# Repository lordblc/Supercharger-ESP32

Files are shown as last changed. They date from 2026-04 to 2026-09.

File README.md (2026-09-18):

Ok, so.. I set out to build upon the work [skonk made that is referred to in this thread](https://www.electricmotorcycleforum.com/boards/index.php?topic=13489.0 "Electric Motorcycle Forum").

My goal was to achieve some additional abilities.  
I wanted to use better hardware. I found his approach to be very clunky and i could not see how I would make it fit on the bike.  
It didn't help that the CAN cable on the bike was very short and limiting me to basically place it close to the fusebox underneath the seat. An area that is already quite space limited.  
Anyway.. I also wanted to include HomeAssistant control as i already have that on my other chargeable vehicles.  

I tried to do the easy approach first, and simply employed CoPilot to just adapt the original code from Arduino to ESP32. This yielded a somewhat result but had issues.  
I referred to that result in the [same forumthread](https://www.electricmotorcycleforum.com/boards/index.php?topic=13748.0 "Electric Motorcycle Forum") as well as here.

Having kept at it and starting from scratch, I formulated an approach as a project manager and set out to make something with Claude as my assistant. I started using the Sonnet 4.5 model, but eventually moved on to Opus 4.6, and later Opus 4.7, Opus 4.8, Fable 5, Opus 5 and Fable 5.1(this code has yet to be updated).  
My approach was to always be in control of what was created and dividing the codebase into smaller chunks where I was able to keep up with what was suggested from the AI.

So, the details are as follows:  
I based this on the LilyGo T-2CAN which has 2 onboard, isolated CAN transceivers ready to go.  
It has 12-24VDC input so can be connected directly to the DC output from the chargers, eliminating one of the PSU's from the original. (I would still highly recommend using an isolated 5VDC for the bike connector to keep these as separate as possible.)  

The controller sits between the bike's CAN bus and the charger's CAN bus and manages the full charge cycle automatically.

Hardware

* [LilyGo T-2CAN (ESP32-S3)] (https://lilygo.cc/products/t-2can "LilyGo Website")
* Charger CAN bus: MCP2515 via SPI at 250 kbps
* Bike CAN bus: ESP32-S3 native TWAI peripheral at 500 kbps
' Tested with Elcon TC HK-J 3300W chargers; multiple units can run in parallel

Bike CAN Bus Interface

The firmware decodes the following from the Zero CAN bus:

* Pack voltage from both the Monolith (BMS 0x388) and PowerTank (BMS1 0x389)
* Pack current from both BMS units (0x408 / 0x409)
* Min and max battery temperatures from both BMS units (0x488 / 0x489), with a range filter to reject the non-thermocouple bytes that the Zero BMS puts in the same CAN frame
* Rated pack capacity in Ah from BMS pack config (0x288 / 0x289)

Charge Control

The charger is commanded over CAN with a target voltage ceiling and a current limit. The firmware implements a three-phase state machine:

* CC / Bulk: Constant current up to the configured power limit. Current ramps up gradually from zero at a configurable rate in W/s. Charge power is reduced as the pack voltage approaches the target through a lookup table (see below).
* CV / Absorption: Once the pack voltage reaches the target, the firmware holds the voltage ceiling and monitors actual charger output current. The charger self-regulates in this region.
* Float / Complete: CV phase ends when actual charger current drops below 2 A (after a minimum 2-minute settle period) or after a 20-minute timeout, whichever comes first. The charger is then stopped and the session is marked complete.  
The charger voltage ceiling is always set to the configured target, not the present pack voltage. This is important — setting it to the present pack voltage would leave the charger with no headroom and it would not regulate correctly.

One key difference here: When charging to 100% the controller will state being in "Bulk" all the way up to 100% but it will be relying on the voltage tables to regulate the power and you can see this reflected in the Current levels tapering off as it gets closer to 100%.

Protection and Cutback

Three lookup tables apply independent power cutbacks. All three are evaluated every cycle and the most restrictive limit wins:

* Voltage cutback: Reduces charge current progressively as the pack voltage approaches the target. The curve is intentionally aggressive toward the top end to avoid voltage overshoot. Thresholds are in decivolts of lifted (under-charge) pack voltage.
* Cold temperature cutback: Reduces charge rate based on the lowest thermocouple reading across both BMS units. Keeps the cells within safe charge rates when cold.
* Hot temperature cutback: Reduces and ultimately stops charging based on the highest thermocouple reading. Charging is stopped completely above 75 C.

Additional guards:

* The charger will not be commanded to start unless a valid pack voltage is present on the CAN bus, preventing phantom starts at boot or after CAN loss.
* Session Wh and Ah counters only accumulate when voltage, current, and a non-zero commanded current are all present simultaneously.
* The charger will throttle the current if the pack is too hot. It will go all the way to zero amps if the temp is too high. This protection also warns the user in the Dashboard.

Session Tracking

Accumulated Wh and Ah for the current charge session
Both CC and CV phase energy are counted using actual charger current, not commanded current

Web Dashboard

The firmware runs a web server on the ESP32. No external server is required. The dashboard shows:

Charging card: actual power, target power, charge current, charge mode (Absorption / Float / Complete)
Per-pack data: voltage, current, Ah capacity, min and max temperature — separately for Monolith and PowerTank
Session Wh and Ah totals
Configurable parameters: target voltage (V), power limit (W), ramp rate (W/s), number of chargers, C+ mode
Status data is delivered via a JSON API endpoint and the page auto-refreshes without a full reload.

WiFi and OTA

* Connects to a saved WiFi network on boot
* Falls back to access point mode if no saved credentials, allowing initial setup via browser
* mDNS hostname for easy access on the local network
* OTA firmware update via browser at /update, protected with HTTP Basic Auth
* MQTT and Home Assistant

Full MQTT discovery is included. The controller publishes itself to Home Assistant automatically with no manual YAML needed. (Tested with EMQX as MQTT server, should also work with mosquitto)

Read-only sensors published:

* actual_volts, target_volts
* monolith_volts, powertank_volts
* charge_amps, monolith_amps, powertank_amps
* monolith_ah, powertank_ah
* monolith_min_temp, monolith_max_temp, powertank_min_temp, powertank_max_temp
* charge_power, target_power_w, max_power_w
* watt_hours, coulombs
* charge mode / phase

Controllable entities:

* Target voltage (V) — number slider
* Target power (W) — number slider
* Ramp rate (W/s) — number slider
* Number of chargers — number slider
* Charging enabled — switch
* Architecture

The firmware uses FreeRTOS on the ESP32-S3 dual core:

Core 0 handles the bike CAN listener and charger CAN output to makes sure the heartbeat is never interrupted by web/mqtt handling clogging the cpu  
Core 1 handles the web server, charge ramp/control logic, and MQTT  
Shared state between cores is protected with mutexes. A 4 KB ring buffer log is available over serial and as a server-sent event stream in the browser.

Required Libraries

* mcp_can by coryjfowler
* PubSubClient by Nick O'Leary
* ArduinoJson by Benoit Blanchon (v6)
* ESP32 Arduino core (includes TWAI driver, ESPmDNS, Update)

Required software

* Arduino IDE with ESP32 board library
* Python (I did my setup initially with python-manager-26.1 for windows)

At current stage it should compile to ~1MB large binary file. I track changes through the VERSION tag that is also visible as reference on the dashboard.  

YOU NEED TO READ ```development_addon -> BUILD_SETUP.md``` AND DO THAT CONFIGURATION TO GET A WORKABLE .bin FILE.  
I cannot stress how important this is. It is directly tied to how OTA works and has been implemented as a safety feature. (stops others from uploading their own firmware)

And if you managed to read this far:  
using arduino_secrets.h is the quickest way to set everything up, but is not required. First boot without configured secrets will default to a welcome page to set everything up with a wlan ap that has the default password set to "12345678" and the AP SSID set to "Supercharger".

This document gets updated whenever there are new changes and i have the time to write them in here.  
DISCLAIMER: I might forget things by the time i get to updating here, but i am trying to keep this updated.

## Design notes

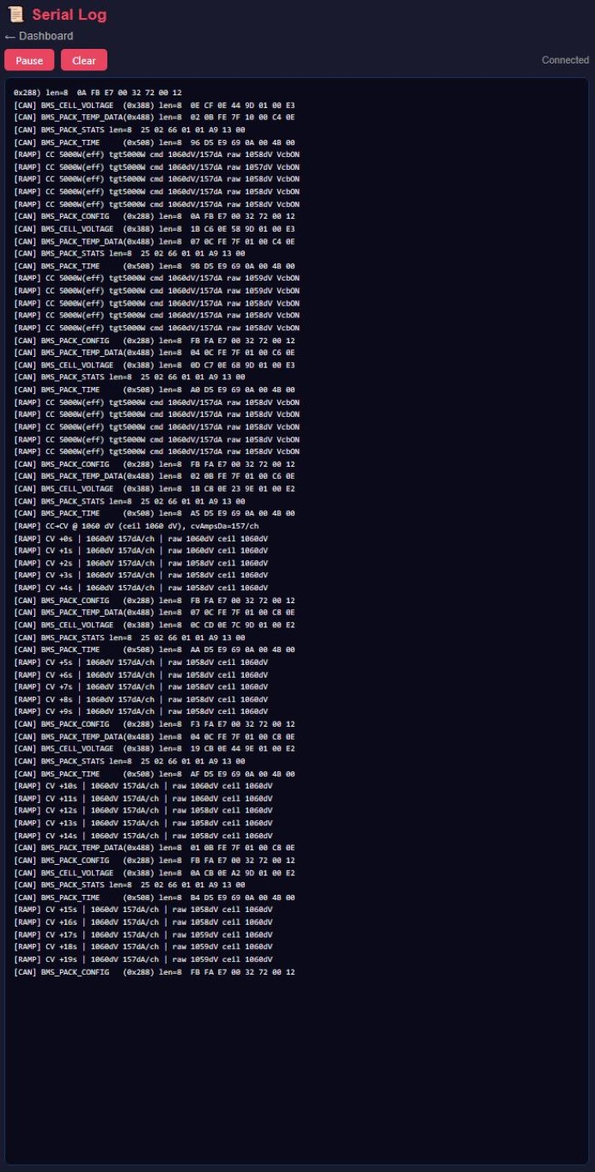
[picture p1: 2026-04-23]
pics/202604231420-Log_768.jpg

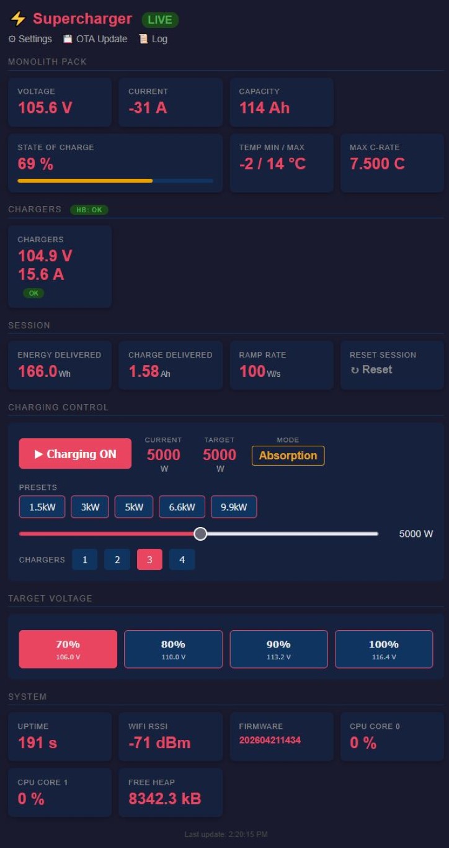
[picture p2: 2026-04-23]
pics/202604231420-Dashboard_Charging_Absorption_768.jpg

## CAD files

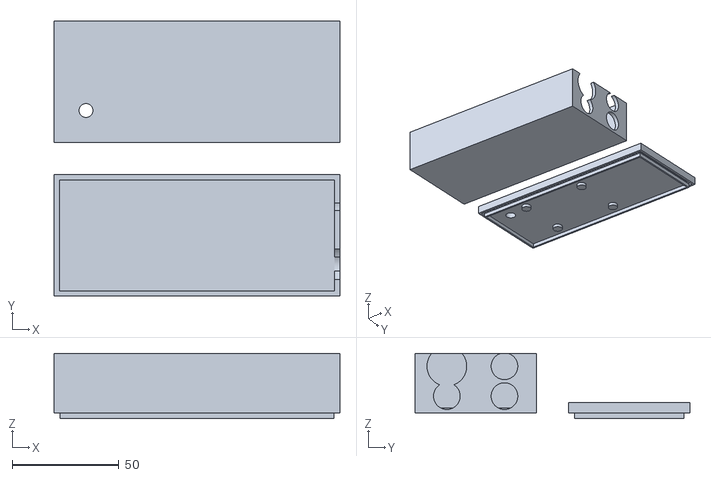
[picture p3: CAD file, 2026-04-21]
cases/supercharger_case_v1.stl
134.0 x 129.0 x 30.5

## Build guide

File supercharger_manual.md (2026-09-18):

# Supercharger 2.5 - ESP32 Controller

## User Manual

A WiFi connected CAN bus controller for charging a Zero motorcycle with up to 4 Elcon TC HK-J 3300W chargers in parallel. You get a web dashboard, optional Home Assistant integration, and firmware updates over the air.

The chargers can be powered from any AC source — a standard home outlet, a dedicated EVSE, or a public charge point. Tested at 3-phase 400 V via an **Easee charge robot** with full functionality.

---

## What changed in 2026-09

If you have used an earlier version, these are the differences you will notice:

- **Charge, Stop and Reset Session now ask first.** A small confirmation box appears in the page (not the browser's own pop-up) before charging starts or stops, before the session counters are zeroed, and before anything that reboots the controller — "Save WiFi & Restart" and the HTTPS toggle.
- **Buttons tell you the truth.** They grey out while the controller is answering, and if it could not do what you asked you get a message instead of silence: *"Controller busy — try again"* when it was mid-tick and applied nothing, and a jump to the login page when your session has expired. Previously the button just changed colour whether or not the command landed.
- **Log and OTA pages when HTTPS is on.** These two stay on plain HTTP by design. Their links now point at `http://...` automatically, so you no longer have to turn HTTPS off to update firmware or read the log.
- **"Keep me signed in" now has a 30-day limit.** A remembered login still survives reboots, but it is forgotten 30 days after you signed in. (If the controller has never had internet time — AP-only use — it has no clock to measure that against and the session keeps working.)
- **The 5–10 second BOOT hold now also signs out every device.** It still clears the saved WiFi network and restarts into AP mode; it additionally drops all logins, including remembered ones. Use it when handing the controller to someone else.
- Two new status banners — **Pack temperature unknown** and **Charger count mismatch** — plus a latched **Charger fault**. See [Status Banners](#status-banners).
- The cycle log's `total_ah` / `total_wh` columns are now per-cycle rather than running session totals — see [The cycle log](#the-cycle-log-cyclescsv).

---

## What You'll Need

- Supercharger 2.5 controller (LilyGo T-2CAN, ESP32-S3 based)
- 1 to 4 Elcon TC HK-J 3300W chargers (powered from any AC source — home outlet, EVSE, or public charge point; tested at 3-phase 400 V on an Easee charge robot)
- Zero motorcycle with CAN bus access to the BMS
- A 2.4 GHz WiFi network (optional, but recommended)
- A phone, tablet, or laptop with a browser for setup
 - A 5VDC Isolated PSU
 - A prototype board
 - A JAI Electronics MX23A18NF1 connector for the Bike connections
 - Some cables (i have used various.. the inter-board connections i could solve with a screened ethernet patch cord)
 - 2 male SuperSeal connectors:

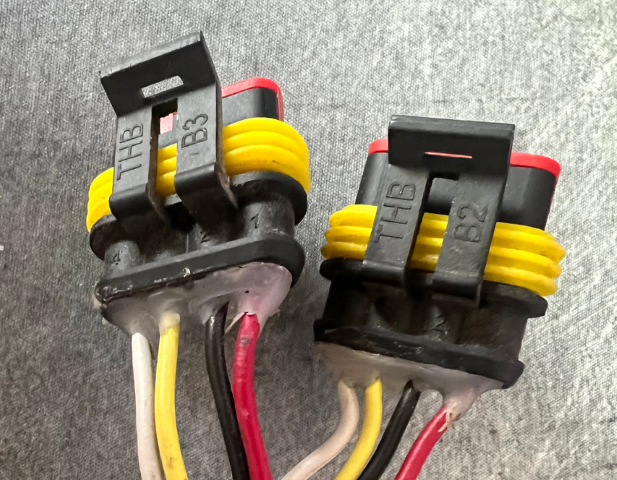
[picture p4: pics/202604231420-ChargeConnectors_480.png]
Charge Connectors


---

## Connecting the Hardware

**The LilyPad T-2CAN Connections**
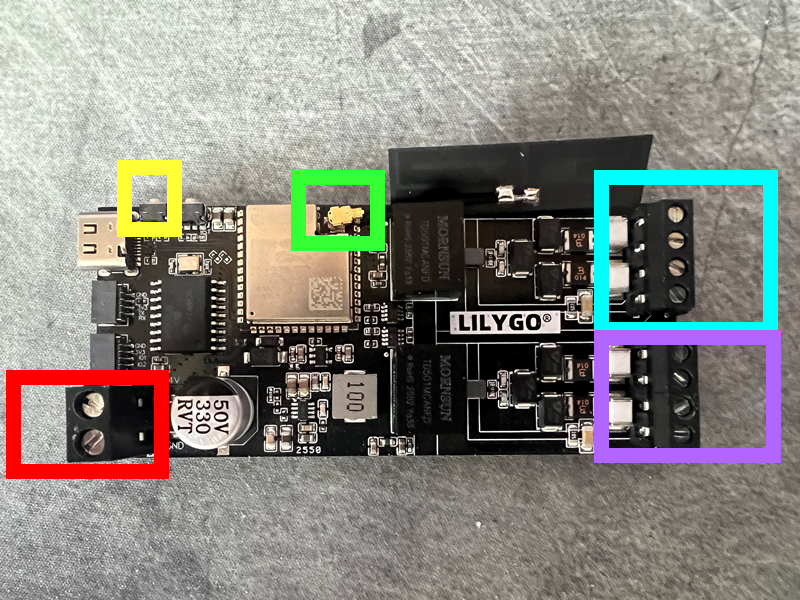
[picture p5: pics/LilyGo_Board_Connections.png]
LilyPad_Board_Connections


In the **Red square** you connect the **red** wire from the chargers to the screw-terminal closest to the USB-C connector. 
You then connect the **black** wire from the same connector to the other terminal, furthest away from the USB-C connector, at the board end.
**Yellow square:** This is the reset button. No connections here, just FYI to where you find it.
**Green square:** You connect the WLAN antenna here. 
**Turqoise square:** You connect the chargers CAN bus here, see seperate image for details.
**Purple square:** You connect the bike's CAN bus here, see seperate image for details.

**The LilyPad CAN Connections**
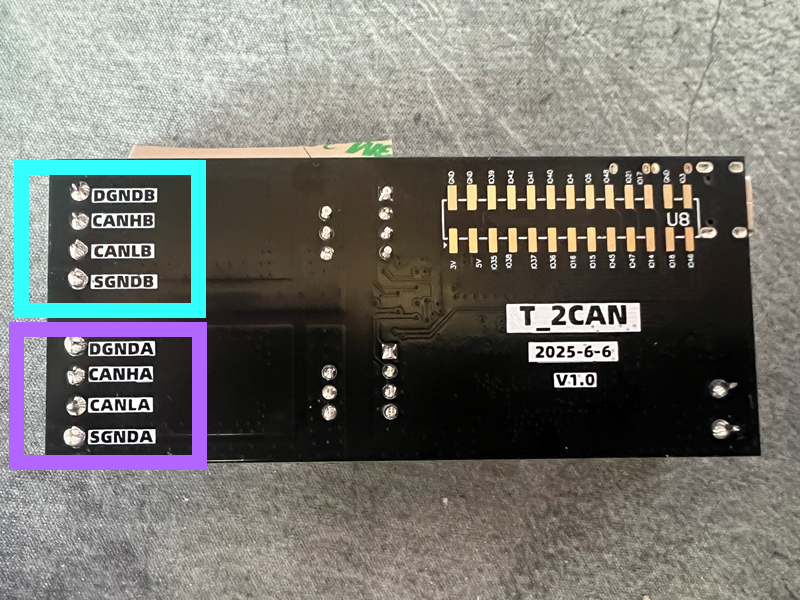
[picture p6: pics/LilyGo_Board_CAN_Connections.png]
Lilypad_Board_CAN_Connections


In the **Turqoise square** you connect the **CANL to the CANLB port** and the **CANH to the CANHB port**. (color code will come later once i have defined the other PCB)
You connect the **GND** cable that is also connected to the **12V-GND** power supply terminals to the **DGNDB** port. 

In the **Purple square** you connect the **CANL -> CANLA port** and the **CANH -> CANHA port** from the bike's CAN bus. Here you will also connect the **separated GND** from bike cable to the **DGNDA port**.

*[MORE TO BE WRITTEN]*

This section covers the 4 pin connector from the Elcon chargers, the 12 VDC supply, CAN bus wiring to the bike, and the splitters used for parallel charger builds.

---

## First Run

Once everything is wired up:

1. Power on the chargers. The 12 VDC from the Elcon cable feeds the controller.
2. The controller boots. Startup takes roughly 2 to 3 seconds.
3. On a fresh unit there are no saved WiFi credentials, so it falls back to AP (setup) mode. If you have connected a laptop to the USB-C port, you'll see a log line on serial saying `No credentials available. Starting AP mode.`
4. Move on to WiFi setup below.

If you want to watch it boot, connect a USB-C cable to the controller and open a serial monitor at 115200 baud.

---

## WiFi Setup (AP Mode)

On first boot, or any time the controller can't find a known network, it creates its own WiFi network for setup.

1. On your phone or laptop, scan for WiFi networks. Look for **Supercharger** (or whatever the builder set as `SECRET_AP_SSID` — see the arduino_secrets.h section below).
2. Connect to it. The default password is **12345678** (or `SECRET_AP_PASS` if the builder set one).
3. Your phone will probably warn you there's no internet. That's fine, ignore it.
4. Open a browser and go to **http://192.168.4.1** or **http://supercharger.local**.
5. You'll see a WiFi Setup page. Enter your home WiFi name (SSID) and password.
6. Hit **Save & Restart**.
7. The controller saves the credentials, reboots, and connects to your home WiFi.

Credentials are stored in non-volatile memory, so you only do this once per network. The AP name and password can also be changed at runtime from the **Settings** page once you're connected — handy if you want a stronger AP password but don't want to reflash.

### Switching to a Different Network Later

If the saved network is gone (moved house, router changed, etc), the controller will try the saved one for 15 seconds, fail, then fall back to AP mode on its own. From there, just redo the setup above with the new credentials.

If the old network is still around and you want to force setup mode anyway, hold the **BOOT** button on the controller for 5 seconds (see the next section). This wipes the saved WiFi credentials and reboots straight into AP mode.

### Fixed AP IP Address (optional)

By default the dashboard lives at **192.168.4.1** in AP mode but at a different, router-assigned address on home WiFi. If you've saved the dashboard as an "app" on your phone's home screen (see the iOS shortcut tip under *Logging In*), that shortcut is pinned to one address — so it only works on one of the two networks.

The **fixed AP IP** option solves this: it makes AP mode serve the dashboard at an IP you choose, so you can point it at the same address your home network gives the controller. One home-screen shortcut then works everywhere.

To set it up: **Settings → Access Point → "Use a fixed AP IP address"**. Tick the box and enter:

- **AP IP Address** — the address the dashboard should answer on (e.g. the address your home router reserves for the controller)
- **Gateway** — usually your home router's IP
- **Subnet Mask** — almost always `255.255.255.0`

Save, then reboot for it to take effect. When the box is unticked, AP mode uses the standard `192.168.4.1`.

Builders can also bake this in at compile time via `SECRET_AP_IP` / `SECRET_AP_GATEWAY` / `SECRET_AP_SUBNET` in `arduino_secrets.h` — see the builder section. The Settings page always overrides the compiled-in values.

### Using the Controller Without Home WiFi

The controller works fine without internet. It'll sit in AP mode and you can use the dashboard by connecting straight to the AP (default **Supercharger**). Everything local still works:

- Charger monitoring
- Power slider and presets
- Start / stop charging
- Battery data
- Live log viewer

Only Home Assistant integration and OTA updates need internet.

---

## The Buttons on the Controller

The LilyGo board has two small side-mounted buttons: **RST** and **BOOT**.

### RST (Reset)

Hardware reset, wired straight to the chip's enable pin. Pressing it cold-boots the controller — equivalent to cycling the 12 V supply from the chargers, just without unplugging anything. The firmware doesn't see the press; the chip simply restarts. Useful when the dashboard is unreachable and you want a clean restart without pulling cables.

### BOOT (User Reset / Recovery)

This is the one to remember. Four hold patterns are recognised:

| Hold time | Action | What it does |
| --- | --- | --- |
| **< 1 s** | Nothing | Ignored — prevents accidental triggers from packaging knocks. |
| **1 – 3 s** | Nothing (logged) | Logged to serial/SSE but no action taken. |
| **3 – 5 s** | Clear auth lock | If the dashboard login is locked (5 failed password attempts from one device, or the device-wide 15-failures-per-minute backstop), this clears all locks and fail counters so the login page becomes responsive again. Has no effect if no lock is currently active. |
| **5 – 10 s** | Clear WiFi + sign out all devices, restart into AP mode | Wipes the saved WiFi SSID/password **and every login session**, including "keep me signed in" logins saved to flash — so a browser that was remembered has to log in again. AP credentials, MQTT settings, charger count, ramp rate, target voltage, and boot defaults all stay intact. Use this when you need to switch the controller to a new network, or when handing it to someone else. |
| **10 s+** | Factory reset | Wipes the entire NVS configuration namespace — WiFi credentials, AP credentials, MQTT settings, charger count, ramp rate, target voltage, and boot defaults. The controller reboots immediately when the 10 s threshold is hit (you don't need to release), so you'll feel the reset rather than wonder if it took. Use this when re-homing the controller to another bike or troubleshooting a stuck configuration. |

The BOOT button still doubles as the chip's bootloader entry button if you happen to hold it while pressing RST — that puts the ESP32-S3 into USB download mode, which only matters if you're flashing over USB.

---

## Logging In

The dashboard is password protected. On first visit your browser shows a login form.

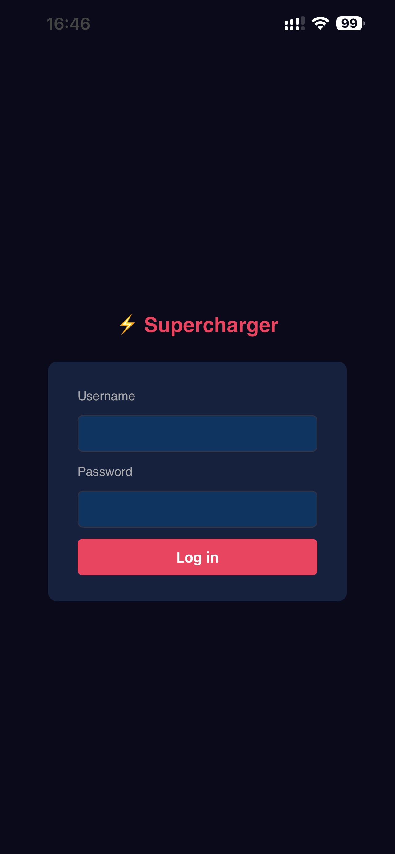
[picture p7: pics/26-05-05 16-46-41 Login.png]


- **Username**: set in `arduino_secrets.h` as `SECRET_OTA_USER`
- **Password**: set in `arduino_secrets.h` as `SECRET_OTA_PASS`

The login form works with your browser's built-in password manager — save the credentials once and it auto-fills on every return visit.

### Keep me signed in

The login form has a **"Keep me signed in on this device"** checkbox, ticked by default. It controls how long the controller remembers you:

- **Ticked** — the session lasts **30 days** and, importantly, **survives a reboot**. The controller cold-boots every time you power the chargers on, so without this your login would be forgotten between every charge session. With it ticked, the controller saves the session to its internal flash and you stay logged in across power cycles. This is what you want for an iOS home-screen shortcut — open the "app" and it's just there, no login prompt.
- **Unticked** — the session lasts **6 hours of idle time** and is **cleared on any reboot**. Use this on a shared or untrusted device.

Either way the session is cleared when you click **Logout** (top of the dashboard). To revoke *all* remembered devices at once — e.g. if a phone is lost — do a factory reset (hold BOOT 10 s+), which wipes all saved sessions along with the rest of the configuration.

While a dashboard tab is open and polling, the session stays alive regardless of the setting.

> **iOS home-screen "app" tip:** open the dashboard in Safari, tap Share → *Add to Home Screen*. You get an app-like icon that opens the dashboard full-screen. Pair it with "Keep me signed in" and the **fixed AP IP** option (see *WiFi Setup*) and the shortcut works the same whether you're at home or charging on the road.

### Login rate limiting and lock-out

Failed login attempts are tracked **per client device** (by IP address), so one misbehaving gadget on your network can't lock everyone else out:

| Attempt | Delay before next try |
| --- | --- |
| 1 – 2 | None (free) |
| 3 | 2 s |
| 4 | 5 s |
| 5 | 15 s — and the login is **hard-locked** |
| 6 | 30 s |
| 7+ | 60 s (cap) |

After **5 failures from one device** the login page returns **423 Locked** and refuses all further attempts from that device regardless of waiting.

On top of the per-device tracking there is a **device-wide backstop**: if **15 login failures from any combination of devices** land within one minute (the signature of someone hopping between addresses to dodge the per-device lock), the controller locks out **all** new logins for 15 minutes.

Three ways to clear either lock:

1. **BOOT button hold 3 – 5 s** — instant, no reboot required (see button section above). Clears the per-device locks, the fail counters, and the device-wide lock in one go.
2. **15 minute auto-clear** — both lock types clear themselves after 15 minutes with no manual intervention.
3. **Reboot** — power cycle or press RST.

Existing open sessions are not affected by a lock — if you are already logged in, the dashboard keeps working while the lock is active. Only new login attempts are blocked.

---

## Finding the Dashboard

Once the controller joins your home WiFi, the easiest way in is mDNS:

- **mDNS**: open **http://supercharger.local** in any browser on the same network. Works on Windows 10+, macOS, iOS, Android (most), and any Linux box running Avahi. No IP guessing required. Also works in AP mode — connect to the controller's AP and the same URL resolves to 192.168.4.1.
- **Router-assigned hostname**: the controller now identifies itself as `supercharger` in its DHCP request. If your router auto-registers DHCP client names into your local DNS (OpenWRT, pfSense, UniFi, MikroTik, etc.), the unit will also appear as `supercharger.<your-domain>` — e.g. `supercharger.iotnet` or `supercharger.lan`. This is a separate path from mDNS and works for any client on the network, including ones that don't speak mDNS.

If neither resolves (some corporate or guest networks block multicast and don't auto-register DHCP names), fall back to:

- **Serial log**: connect USB-C and open a serial monitor at 115200 baud. Look for a line like `[WIFI] Connected (prefs). IP: 192.168.1.42`.
- **Router**: log into your router's admin page and check the DHCP client list. The controller usually shows up as "espressif" or similar.

Type the IP into any browser on the same network and the dashboard loads.

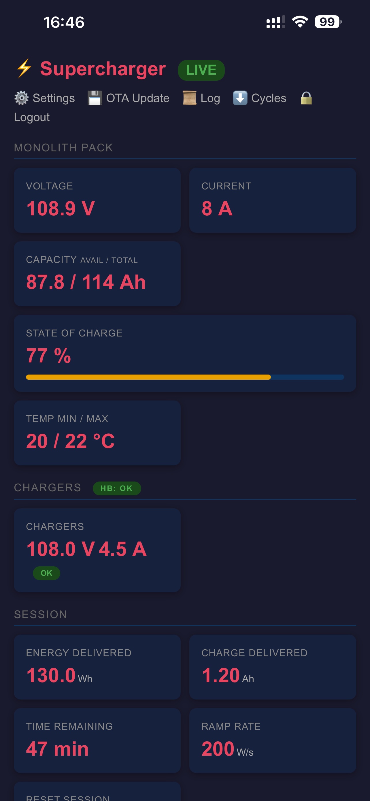
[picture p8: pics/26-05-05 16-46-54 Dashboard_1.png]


---

## Using the Dashboard

The dashboard auto refreshes every 2 seconds.

### Battery Sections

**Monolith Pack** shows voltage, current, capacity, state of charge, temperature, cell balance, and BMS board temperature. Always visible.

- **State of Charge** is read straight from the BMS (CAN frame `0x188` byte 0) — the same coulomb-counted number the bike's own dashboard uses, so the two should agree closely. If the BMS hasn't broadcast a status frame yet (typically the first few seconds after the bike wakes), the card falls back to a voltage-curve estimate and is labelled `(est.)` until the BMS catches up.
- **Capacity** shows `available / total Ah` — the available number is the nominal pack AH multiplied by the current SoC, so it tracks how much charge is actually left in the pack right now (e.g. `57.0 / 114 Ah` at 50%) rather than just printing the constant nameplate value.
- **Cell Balance** shows the spread between the highest and lowest individual cell voltage in the pack (max − min, in mV). The BMS broadcasts one cell at a time on CAN frame `0x388`, cycling through all 28 cells roughly every 3 seconds; the controller accumulates all readings and keeps the balance current. The value is colour-coded:
  - 🟢 **Green** — less than 10 mV: cells are well-balanced, no action needed.
  - 🟡 **Amber** — 10 – 50 mV: mild imbalance, worth watching over time.
  - 🔴 **Red** — more than 50 mV: significant imbalance; consider a full charge to 100 % to let the BMS balance.
  The tile shows "—" for the first few seconds after the bike is connected, while the controller is still collecting the first full round of cell readings.
- **BMS Temp** shows the temperature of the BMS circuit board itself (CAN frame `0x488` byte 1 — reported as "Controller Temp" by third-party diagnostic tools). This is separate from the min/max cell temperatures in the Temp card, which reflect the cell pack interior.

**PowerTank Pack** shows the same fields (except cell balance and BMS Temp, which are not decoded for the PowerTank) if a PowerTank is present. It's auto detected within 10 seconds of the first bike CAN frame. If it doesn't show up in that window, the section stays hidden.

### Status Banners

A coloured banner across the top of the dashboard tells you when something needs your attention. The colour tells you how serious it is:

| Colour | Meaning |
| --- | --- |
| **Red** | Charging has stopped, or cannot start. |
| **Amber** | Charging continues, but at reduced power. |
| **Blue** | Advisory only. Charging is unaffected. |

Only one banner shows at a time — the most serious condition wins, so you never get two messages that contradict each other. Each one clears itself as soon as the condition passes and needs no acknowledging — with one exception: **Charger fault** is latched, and only clears when you switch charging off and on again.

Separately from these, a red **"No WiFi"** banner means the controller can't reach your home WiFi and is running its own AP. Reach the dashboard via `http://<ap-ip>` or `http://supercharger.local`. It reconnects automatically when home WiFi comes back.

#### Red — charging has stopped



| Banner | What it means | What to do |
| --- | --- | --- |
| **Pack too cold** | Pack is below **0 °C**. Charging a cold lithium cell plates metallic lithium onto the anode, which permanently reduces capacity and can eventually short the cell. This is the one limit you should never work around. | Nothing. Charging resumes on its own once the pack warms past 2 °C. Riding the bike, or moving it somewhere warmer, is the quickest way. |
| **Pack too hot** | Pack is above **45 °C**, the cell manufacturer's charging limit. | Nothing. Resumes on its own below 43 °C. If it happens without hard riding beforehand, check for blocked airflow around the pack. |
| **Pack voltage too low** | Pack is below **70 V** (2.5 V per cell). Below this level the copper current collector inside the cells starts to dissolve, and charging normally can create an internal short. | **Do not force it.** This should never happen in normal use — the bike's own BMS cuts out well above this. Have the pack checked by a technician. |
| **Pack temperature unknown** | The BMS is not reporting a valid pack temperature — the sensor is reading as disconnected, or the frame carrying it has stopped arriving. Without a temperature the hot cutback and the 45 °C limit have nothing to work from, so the controller will not charge. | Nothing, if it's brief — charging resumes as soon as valid temperature data returns. If it persists, the pack's temperature sensor or its wiring needs checking. |
| **No data from bike** | The controller has lost contact with the bike's BMS, so it can't see pack voltage or temperature. It will not charge blind. | Check the charge connector is fully seated and the bike is powered on. Charging resumes within a second of data returning. |
| **Charger fault** | A charger is reporting a **hardware fault or an over-temperature**, or its output voltage has run well above the voltage asked for. (The other things an Elcon reports — AC input out of range, "no battery yet", comms timeout — are shown on the charger card but deliberately do *not* stop a charge: they come and go on their own.) A fault has to persist for three seconds before it counts, and the first five seconds after you press Charge are ignored, because a charger that has been sitting idle reports its starting state until it has seen a few commands. | Find and fix the cause (see the charger's own status card), then press **Stop** and **Charge** again. This one does *not* clear itself: it stays latched until charging is switched off and back on, so a unit that faults and then drops off the bus can't quietly resume. |
| **Charger count mismatch** | More chargers are answering on the CAN bus than the charger-count setting says are installed. Since all units get the same broadcast command, each extra one delivers a full share on top of what was asked for. | Set the charger count in Settings to match what's actually connected. Charging resumes as soon as the two agree. |
| **Too many chargers** | More than four chargers are answering on the CAN bus. The controller divides commanded current between the chargers it knows about, so an extra unit would make every charger deliver more than intended. | Disconnect the extra charger, or give the chargers distinct CAN instance IDs, before charging. |

#### Amber and blue — charging continues



| Banner | What it means | What to do |
| --- | --- | --- |
| **Reduced power — pack warm** | Pack temperature has crossed the hot-cutback threshold and power is being trimmed back. Normal on a hot day or after a fast ride. | Nothing. It speeds back up as the pack cools. |
| **Reduced power — at cell current limit** | The power you asked for needs more current than the cells are rated to accept (1 C), so it has been capped. | Nothing, unless you'd rather not sit at the limit — in which case lower the power setting. |
| **Ignoring bad data from bike** | Some CAN messages from the battery are arriving corrupted and are being discarded rather than acted on. | Nothing if it's occasional. If it persists, check the CAN wiring and connector for damage or a loose shield. |

### Chargers

One card per detected charger, with voltage, current, and status. Chargers appear automatically within a few seconds of being connected. A heartbeat badge at the top shows whether the controller is successfully talking to the bus.
**NOTE:** The DigiNow pack this was programmed against, came with one(and same) ID programmed towards all 3 chargers. If you have this setup, the system will only detect one charger, but you can set this static as a work-around.

### Charging Control

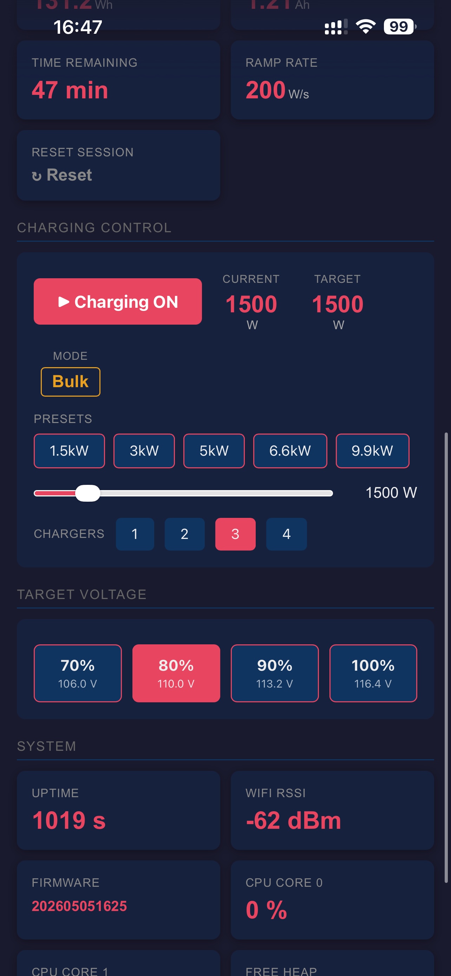
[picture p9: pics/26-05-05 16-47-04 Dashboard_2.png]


**ON / OFF button**: enables or disables charging. When disabled, the controller commands zero power immediately, no ramp down.

**Power slider**: set your target power in watts. The controller ramps from current to target at 50 W(adjustable) per second, so jumping from 500 W to 3300 W takes about a minute to get there. This is intentional.

**Preset buttons**: auto scale based on how many chargers you have connected. Just tap one to jump to that power.

Presets per charger count:

| Chargers | Preset 1 | Preset 2 | Preset 3 | Preset 4 | Preset 5 |
| --- | --- | --- | --- | --- | --- |
| 1 | 500 W | 1000 W | 1650 W | 2200 W | 3300 W |
| 2 | 1000 W | 2000 W | 3300 W | 4400 W | 6600 W |
| 3 | 1500 W | 3000 W | 5000 W | 6600 W | 9900 W |
| 4 | 2000 W | 4000 W | 6600 W | 8800 W | 13200 W |

The preset number (1–5) stays consistent across charger counts — Preset 2 always represents the second-lowest power level for however many chargers you have. This is also the column used for the Boot Defaults preset setting (see Settings page below).

**Chargers 1 / 2 / 3 / 4 buttons**: these set how many chargers the controller accounts for when scaling the preset table and the slider's maximum. They have **no effect on what the chargers actually do** — the controller broadcasts a single CAN command and all chargers that share the same CAN ID respond to it simultaneously, regardless of this setting. This is the typical DigiNow setup where all chargers are programmed with the same ID. If your chargers each have a *distinct* CAN ID, this count would become meaningful and the button should be left at the number physically connected rather than adjusted freely.

**Auto behavior**: when chargers first appear, the controller auto enables charging at the lowest preset. When they all disappear (e.g. you unplug), it auto disables. You don't have to babysit it.

### Charge Limit Presets (% of Full)

Below the power slider you'll find a row of **70 / 80 / 90 / 100 %** buttons. These set the **target pack voltage** — i.e. how full the controller will let the pack get before it stops feeding it. They are the key knob for trading range against pack longevity, and they directly drive the CC / CV state machine described below.

| Preset | Pack voltage ceiling | Roughly what it gives you |
| --- | --- | --- |
| 70 % | 106.0 V | Daily commute / short rides. Easiest on the cells; a useful default if the bike sits for days between rides. |
| 80 % | 110.0 V | Recommended day-to-day setting. Most of the range, much less stress than topping right out. |
| 90 % | 113.2 V | Longer rides. A gentle compromise. |
| 100 % | 116.4 V | Use the day before a long ride or for periodic balancing. The pack will sit slightly hot and at full voltage, which accelerates calendar ageing if you leave it there for days. |

The percentages are based on the Zero monolith pack open-circuit voltage curve (28S Li-ion NMC). The mapping is not perfectly linear with state of charge (Li-ion never is), but it's close enough that "80 %" lands you near 80 % SOC.

The dashboard remembers your last selection across reboots. The same setting is exposed over MQTT (`target_volt_v`) for Home Assistant automations — e.g. set 100 % only the night before a trip.

### Bulk / Absorption / Float — How the Controller Stops Charging

The controller runs a three stage automatic charge cycle, named after the standard solar/battery-charging convention so what's happening on the bike maps to what you'd expect from any other smart charger.

**Stage 1 — Bulk** *(internally CC, "Constant Current")*
This is the main charging phase where most of the energy goes in. The controller commands the chargers to deliver the power you've set on the slider, ramping up at 50 W/s (adjustable). Pack voltage rises gradually as the cells absorb energy. The dashboard phase indicator reads **Bulk**. Voltage and temperature limits (see `battery_tables.h`) only apply in this phase — they trim power back as the pack gets close to full or warm.

**Stage 2 — Absorption** *(internally CV, "Constant Voltage")*
When the pack reaches the target voltage, the controller switches to **Absorption**. It holds the pack at that voltage and lets the chargers reduce current as the cells equalize and finish topping up. You'll see the current target falling on the dashboard while charging continues at a lower level. This stage finishes when one of two things happens, whichever comes first:

- Actual delivered current drops below **2 A total** (after a 2 minute settling window).
- **1 hour safety timeout** finishes.

The 1 hour timeout is generous on purpose — better to give all cells a long, well-paced equalization than to cut absorption short. The absorption stage is short at 70–80 % targets and longer at 90–100 %, because higher charge levels need more time to equalize across the pack. Lower presets shorten or eliminate this stage entirely. That's why 70 % or 80 % charges take proportionally less time. Most cell stress happens during absorption at over 90 % charge — lower presets avoid most of it.

**Stage 3 — Float** *(internally DONE)*
Charging stops, the chargers go silent, and the cells rest. The dashboard shows **Float**. Energy totals (Wh, Ah) stop updating. The controller stays in this stage indefinitely until either the user turns charging off, or the pack sags below the re-engage threshold (see below) and a new cycle starts.

**Time Remaining card** (Session row): a coulomb-counting estimate of how much longer charging will take to reach the active **target preset** (not 100 %). It's the same idea as the bike's own dashboard timer, but it tracks the user-chosen ceiling. During Bulk it divides the remaining Ah by the present pack current and smooths the result with a small EMA filter so a brief current dip doesn't jump the readout. During Absorption it shows the remainder of the 1 hour safety countdown — that's the upper bound; the stage usually ends earlier on the current taper. Reads "—" when the controller has no useful number to show (e.g. before current settles, or once the pack is already at/above the target).

Note that this isn't "float" in the lead-acid sense of holding a maintenance voltage on the pack — Li-ion doesn't want that. It's a *resting* float: the chargers are off and the BMS is left alone. The name keeps the dashboard consistent with what most users already know from solar / RV setups.

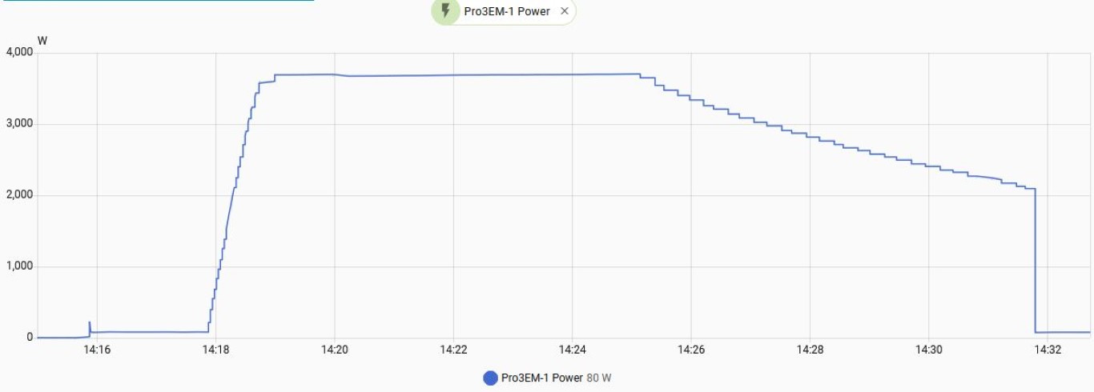
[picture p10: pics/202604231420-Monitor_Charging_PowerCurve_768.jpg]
Dashboard Screenshot


Screenshot from my Home Assistant power monitor. This monitor sits in front of the 230 V → 400 V transformer, so the absolute watts aren't precise — but it does cleanly show the bulk ramp-up, absorption taper, and float (charger off) stages.

**Recovery transitions** — the controller doesn't just sit in Float forever:

- **Absorption → Bulk** if pack voltage drops more than 1 V below the limit after switching to Absorption, it switches back to Bulk.
- **Float → Bulk** the threshold depends on the preset you've chosen:
  - **70 % or 80 %**: pack must drop more than **2 V** below the target before a new cycle starts. Frequent small top-offs are fine in this gentle SoC range.
  - **90 %, 100 %**, or any custom target above 110.0 V: the controller waits for the pack to sag all the way down to the **80 % level (110.0 V)** before re-engaging. The cycle is wider (more voltage sag per top-off), but the pack spends far less time hovering near full charge — which is what actually wears Li-ion cells. The trade-off is deliberate: at 100 %, you'll see the pack discharge from 116.4 V down to 110.0 V before the chargers kick back in.

**Already at target when you start**: if you turn charging on and the pack is already at or above the chosen preset's voltage (e.g. you set 80 % but the bike is at 84 %), the controller skips Bulk and Absorption entirely and goes straight to **Float** without ever sending a start command to the chargers. The same Float → Bulk re-engage rules above then decide when (if ever) to start a new cycle. No wasted brief charge bursts at the top of the SoC range.

Bulk's first job at the start of every session is this comparison, and it waits for real telemetry before making it — so if the controller powers up with charging already enabled (see Boot Defaults) but the bike's BMS hasn't reported in yet, the decision is deferred a tick rather than skipped. The serial log records which way it went:

```
[RAMP] Start: no charge needed - pack 1112 dV (~84%) >= target 1100 dV (~80%). FLOAT; will top up if the pack sags.
[RAMP] Start: BULK - pack 1050 dV (~68%) -> target 1100 dV (~80%)
```

#### Changing the target mid-charge

You can move the % preset at any time and the controller re-evaluates immediately — you don't have to stop and restart charging.

| You change the target to… | Pack is… | What happens |
| --- | --- | --- |
| **A higher preset** (e.g. 80 → 100 %) | below the new target | Returns to **Bulk** and carries on charging, from Float or from Absorption. |
| **A higher preset** | already within 1 V of the new target | Stays where it is. Not worth a whole cycle for under a volt. |
| **A lower preset** (e.g. 80 → 70 %) | above the new target | Goes straight to **Float**. The chargers stop; no partial cycle at a voltage the pack is already past. |
| **A lower preset** | still below the new target | Keeps charging, and stops at the new lower ceiling. |

After dropping to a lower preset, the normal Float → Bulk re-engage rules take over — so at 70 % the pack has to sag to 104.0 V before a fresh top-off begins. Lowering the target never leaves the controller stuck: a lower ceiling only makes the re-engage threshold lower too, and the pack always sags there eventually.

**Practical implication of the % presets**: choosing 70 % doesn't just mean "stop earlier" — it also means a much shorter Absorption phase (or none at all if the ceiling is below where the pack would naturally taper). That's why low presets feel quick: the bulk of cell stress in a Li-ion charge is during Absorption at high voltage, and you're skipping most of it.

### Cell Protection Limits

Everything above is about *how much* you charge. This section is about the hard boundaries the controller will not cross regardless of what you ask for.

The Zero monolith uses **Farasis IMP06160230P25A** cells — 25 Ah NMC pouch cells, 28 in series. The limits below come straight off that cell's datasheet, and they override the power slider, the presets, MQTT commands and the boot defaults alike.

| Limit | Value | Why |
| --- | --- | --- |
| Charging temperature | **0 to 45 °C** | Datasheet charging range. Below 0 °C charging plates lithium; above 45 °C it accelerates cell degradation. Outside this range the controller refuses to charge at all and shows a red banner. |
| Maximum charge current | **1.0 C** (25 A per cell) | Datasheet maximum. Applied to the *total* pack current before it's divided between chargers, so it holds no matter how many chargers are connected or what the cutback tables allow. |
| Minimum pack voltage for charging | **70 V** (2.5 V/cell) | Below this the copper current collector inside the cells dissolves and charging can create an internal short. The controller refuses; this needs a technician, not a charger. |
| Maximum pack voltage | **116.4 V** (4.157 V/cell) | The 100 % preset. Inside the cell's 4.15–4.20 V constant-voltage window, with margin. |

Two things worth understanding about how these interact with the cutback tables in `battery_tables.h`:

- The **cutback tables shape** charge current inside the safe window — they taper power as the pack warms or approaches full. The **hard limits above are the boundary** of that window. Two independent layers: if a future firmware change broke one, the other still holds.
- A temperature limit being hit is an **outright stop**, not a cutback. That's the difference between the red "Charging paused" banners and the amber "Reduced power" one. Amber means it's still charging.

**Sub-zero charging is not user-overridable.** There is no setting to bypass it, deliberately. If you need to charge a cold pack, warm the pack — ride it, or move the bike indoors.

**Implausible readings are discarded.** Pack voltage arriving from the bike outside 42–117.6 V (1.5–4.2 V/cell) is treated as a corrupted CAN frame and thrown away rather than acted on. If corrupted frames keep arriving, the blue "Ignoring bad data" banner appears; if they're *all* corrupt the controller ends up with no fresh data and stops charging with the red "No data from bike" banner. Either way it never computes a charge current from a bad voltage reading.

### System Info

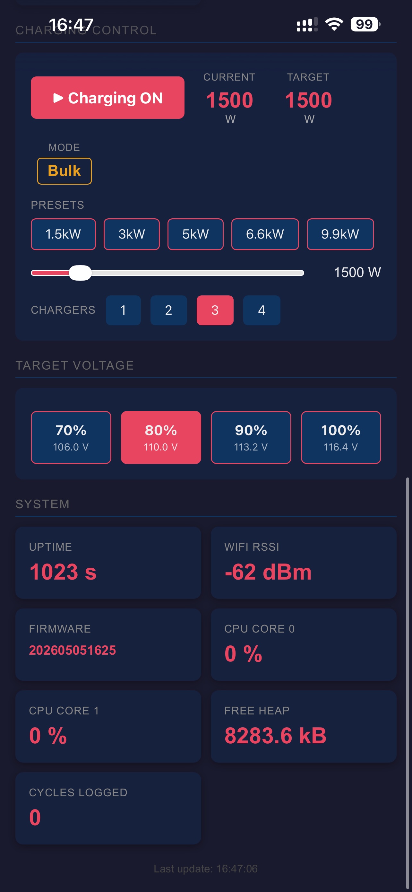
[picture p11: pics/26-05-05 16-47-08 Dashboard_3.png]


At the bottom: uptime, WiFi signal, firmware version, CPU load per core, free heap, and the number of charge cycles logged to the on-device data file. Useful when you're debugging.

#### The cycle log (`/cycles.csv`)

One row is appended per **completed** charge cycle — that is, a cycle that actually ran an absorption phase and finished in Float. A charge that never entered absorption (for example, the pack was already above the target when you pressed Charge) is not recorded. Download it with **⬇ Cycles** on the dashboard.

**A row is one bulk → absorption → float leg, not one plug-in.** Anything that sends the controller back to Bulk starts a fresh row: pressing Stop and then Charge again, a top-up after the pack has sagged out of Float, or the pack briefly sagging under load during absorption. So a single evening on the charger can produce several rows, and a leg that gets interrupted before reaching Float is simply not written. Don't add the rows up to get "energy delivered this plug-in" — they are per-leg figures.

The columns are: `timestamp, preset_pct, start_v, end_v, start_soc, end_soc, start_temp, end_temp, total_ah, total_wh, bulk_min, absorption_min, charger_count, abort_reason`.

`abort_reason` says how absorption ended:

| Value | Meaning |
|---|---|
| `0` | `current_taper` — absorption ran to completion, charge current tapered to the finish threshold. This is the normal, healthy ending |
| `1` | `cv_timeout` — absorption hit its one-hour safety limit and was stopped. The cells may not have finished balancing |
| `2` | `above_target` — absorption was cut short because the pack ended up above the target voltage: either you lowered the charge limit mid-charge, or the pack was lifted above it from outside (charged elsewhere, or regen) |

> **Changed in this version — `total_ah` and `total_wh` are now per-cycle.**
> They record the amp-hours and watt-hours delivered **by that leg alone**, accumulated tick by tick from the moment bulk charging started. Pressing **Reset Session** in the middle of a charge no longer affects them — that button zeroes the dashboard's session counters only, and the figures written to the cycle log are kept separately. In earlier firmware these two columns carried the running *session* totals instead, so any cycle that followed another one without a session reset in between reported everything accumulated since the reset, not just its own charge. Rows written by older firmware are still in the file and still session-to-date — if you are analysing a mixed file, treat rows older than this firmware's first entry accordingly. `total_ah` also no longer wraps above 655.35 Ah.

### Log Viewer

Click the Log link, or go to **/log**. Live serial log in your browser, updated in real time. Good for diagnosing CAN bus issues without needing a USB cable.

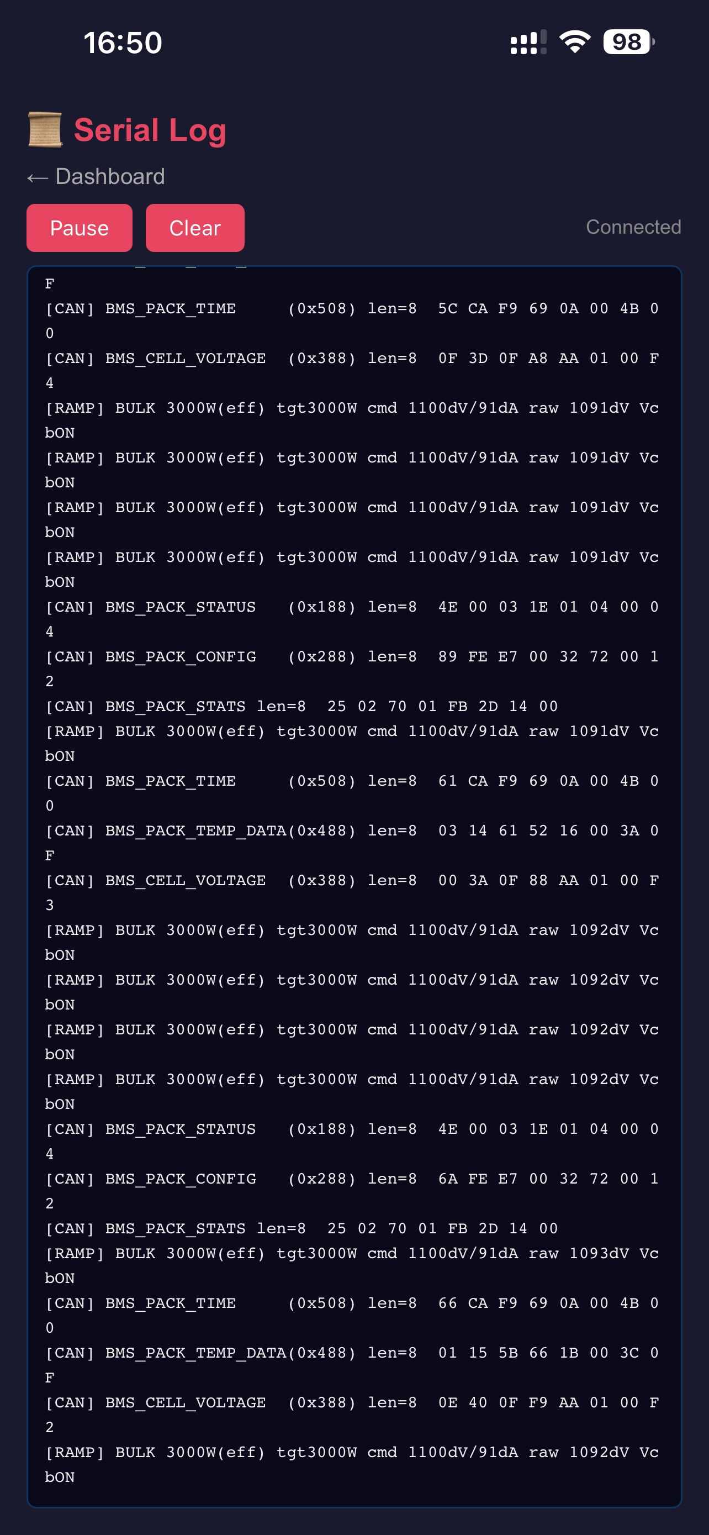
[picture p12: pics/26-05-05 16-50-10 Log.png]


---

## Settings Page

Click **Settings** in the dashboard navigation bar, or go to **/settings**. All settings are saved to non-volatile storage immediately — they survive reboots and OTA updates.

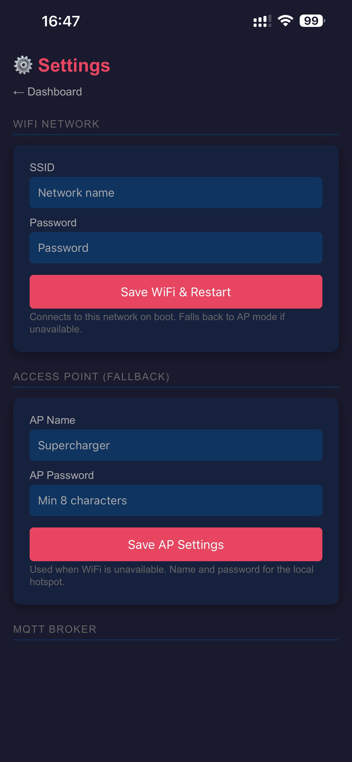
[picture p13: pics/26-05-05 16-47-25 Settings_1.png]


### WiFi Network

Set the SSID and password for the home WiFi network the controller should join. Changes require a restart (the save button triggers one automatically).

### Access Point (Fallback)

The name and password for the controller's own hotspot, used when home WiFi is unavailable. Minimum 8 characters for the password. The built-in default is `Supercharger` / `12345678` — change this if the device will be used in shared spaces.

**Use a fixed AP IP address** — tick this to make AP mode serve the dashboard at a specific IP instead of the default `192.168.4.1`. Enter the **AP IP Address**, **Gateway**, and **Subnet Mask** (usually `255.255.255.0`). The point is to mirror your home network so a single iOS home-screen shortcut works in both AP mode and on home WiFi — see *Fixed AP IP Address* under WiFi Setup. The change applies on the next reboot. Leave the box unticked to keep `192.168.4.1`.

### MQTT Broker

Configure the broker address, port, username, and password for Home Assistant integration. TLS (SSL) can be enabled — if you enable it you must also paste the broker's CA certificate (PEM format) into the text area that appears. Saving reconnects the MQTT client immediately without a reboot.

### Charger Hardware

Sets how many chargers the controller expects to see on the CAN bus (1 – 4). This controls which row of the preset table is used and divides the commanded current evenly across units.

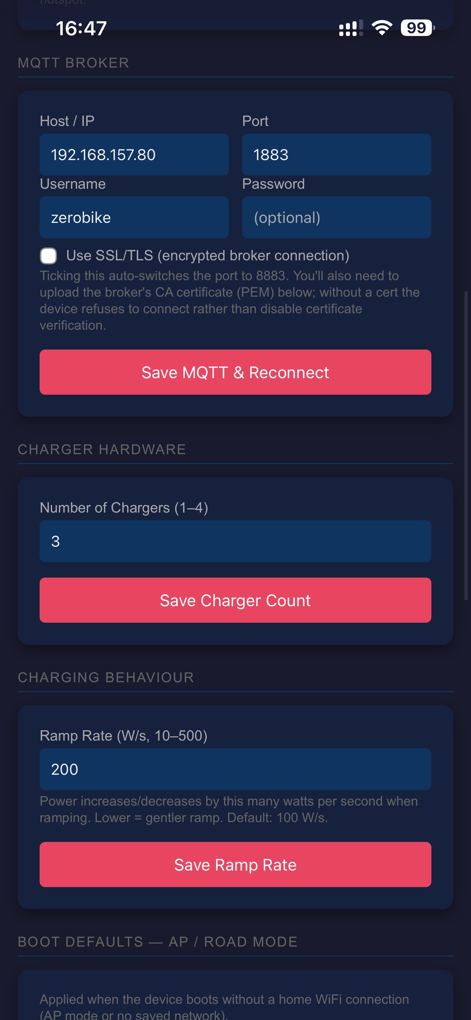
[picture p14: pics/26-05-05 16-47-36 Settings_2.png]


### Charging Behaviour

**Ramp Rate (W/s)**: how many watts the controller adds or removes per second when stepping toward a new target. Lower values give a gentler ramp. Default is 100 W/s; valid range 10 – 500.

### Boot Defaults — AP / Road Mode

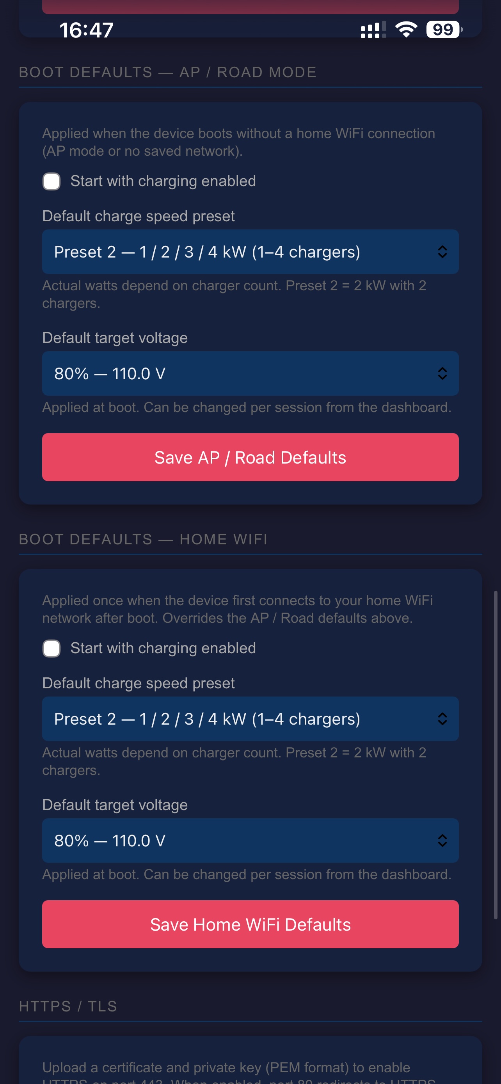
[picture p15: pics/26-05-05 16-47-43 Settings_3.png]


These settings define the charging state the controller wakes into on every boot **when no home WiFi connection is available** (AP/road mode). They are applied immediately in the boot sequence before any WiFi connection is attempted.

| Setting | What it controls |
| --- | --- |
| **Start with charging enabled** | If checked, charging is active as soon as the controller boots. If unchecked, you must press ON from the dashboard. Default: off. |
| **Default charge speed preset** | Which preset column (1 – 5) to use as the initial power target. Actual watts depend on charger count — see the preset table above. Default: Preset 2 (1 / 2 / 3 / 4 kW). |
| **Default target voltage** | Which charge limit preset (70 / 80 / 90 / 100 %) to start with. Default: 80% (110.0 V). |

Click **Save AP / Road Defaults** to persist. These take effect on the next boot.

**With "Start with charging enabled" on**, the controller still checks the pack against the target before doing anything — it waits for the bike's BMS to report in, compares pack voltage to the target preset, and goes straight to Float if no charge is needed. So booting with charging enabled and a pack already above the target does *not* produce a brief charge burst. If the BMS is slow to report, the decision is deferred rather than skipped.

### Boot Defaults — Home WiFi

The same three settings, applied **once** when the controller first joins your home WiFi network after boot. They override the AP / Road defaults above at that moment. Subsequent WiFi drops and reconnects during a session do not re-apply them — once applied they stay applied for that session only.

| Setting | What it controls |
| --- | --- |
| **Start with charging enabled** | As above, but for home WiFi sessions. |
| **Default charge speed preset** | As above, but for home WiFi sessions. |
| **Default target voltage** | As above, but for home WiFi sessions. |

Click **Save Home WiFi Defaults** to persist. These take effect on the next boot once the controller connects to home WiFi.

**Typical use**: set the AP / Road defaults conservatively (charging off, low preset, 80% target) for when the controller is connected to the bike at an unfamiliar location. Set the Home WiFi defaults to your preferred daily charging behaviour (charging on, your usual preset, 80% target) so you don't have to touch the dashboard each time you plug in at home.

### HTTPS / TLS (Optional)

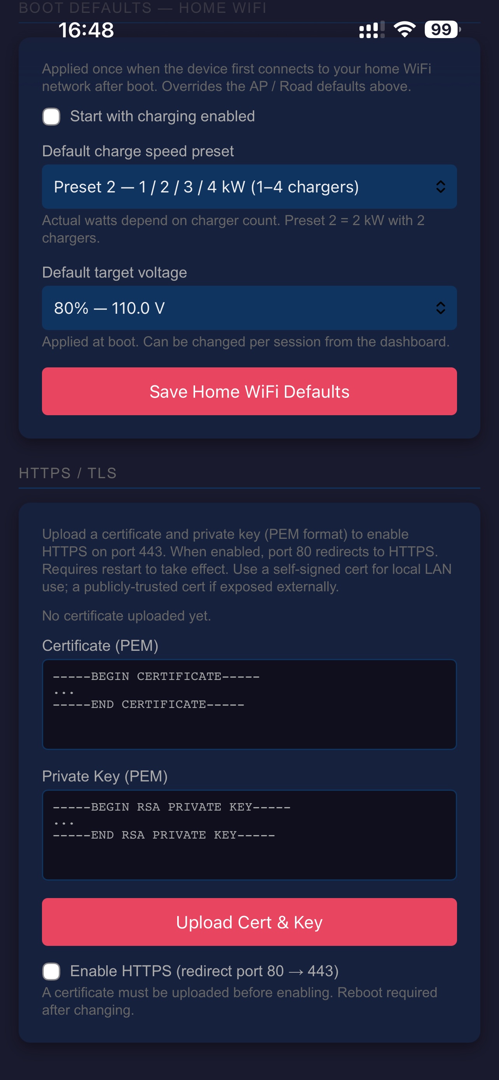
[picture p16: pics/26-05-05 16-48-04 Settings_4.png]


The controller can serve the dashboard over HTTPS (port 443) with a TLS certificate you supply. When enabled, port 80 redirects all traffic to port 443.

**Setup — one time per certificate:**

1. Generate or obtain a certificate and private key in PEM format. A self-signed cert is fine for a LAN device.
2. Open **Settings → HTTPS / TLS**.
3. Paste the certificate PEM into the **Certificate** box and the private key PEM into the **Private Key** box.
4. Click **Upload Cert & Key**. The PEM data is saved to NVS on the controller — it survives reboots and OTA updates.
5. Tick **Enable HTTPS** and confirm. This saves a flag to NVS.
6. Reboot the controller (RST button or power cycle). Port 443 starts automatically.

**Notes:**

- First browser visit to `https://<ip>/` will show a security warning for a self-signed cert. Accept it once (add a permanent exception). After that the browser connects silently.
- To disable HTTPS: untick **Enable HTTPS** in Settings (or POST `{"enabled": false}` to `/api/tls`) and reboot. The controller falls back to plain HTTP on port 80.
- `/update` (OTA), the live log stream (`/api/log/stream`), the log viewer page (`/log`) and the old `/save` setup form stay on **plain HTTP port 80** even when HTTPS is active — there is no TLS story for a multipart firmware upload or a long-lived log stream. You do **not** need to disable HTTPS to reach them: the dashboard's **Log** and **OTA** links switch themselves to `http://<address>/...` when the page was loaded over HTTPS, so they just work. The login page is also served on port 80 for the same reason, so these pages can sign you in on their own. The cycle-data download (**⬇ Cycles** on the dashboard) works over HTTPS.
- The HTTPS server runs in its own FreeRTOS task. No extra polling is needed; the plain HTTP port 80 also stays up to serve the redirect.
- Cert and key are stored in NVS under keys `tls_cert`, `tls_key`, and `https_en`. A factory reset (10 s BOOT hold) clears them along with all other settings.

---

## For Builders: First Time Flashing

### Required Libraries

Install these from the Arduino Library Manager:

- `mcp_can` by coryjfowler
- `PubSubClient` by Nick O'Leary

The rest (`ESPmDNS`, `driver/twai.h`) ship with the Espressif ESP32 Arduino core, no separate install needed.

### Arduino IDE Board Settings

Install ESP32 board support via Boards Manager (search "esp32" by Espressif Systems) if you haven't already. Then match these settings under the Tools menu. These are LilyGo's recommended settings for the T-2CAN:

| Setting | Value |
| --- | --- |
| Board | ESP32S3 Dev Module |
| Upload Speed | 921600 |
| USB Mode | Hardware CDC and JTAG |
| USB CDC On Boot | Enabled |
| USB Firmware MSC On Boot | Disabled |
| USB DFU On Boot | Disabled |
| Upload Mode | UART0 / Hardware CDC |
| CPU Frequency | 240MHz (WiFi) |
| Flash Mode | QIO 80MHz |
| Flash Size | 16MB (128Mb) |
| Partition Scheme | 16M Flash (3MB APP/9.9MB FATFS) |
| Core Debug Level | None |
| PSRAM | OPI PSRAM |
| Arduino Runs On | Core 1 |
| Events Run On | Core 1 |
| Erase All Flash Before Sketch Upload | Enabled |
| JTAG Adapter | Disabled |
| Zigbee Mode | Disabled |

The 3 MB APP partition is what makes OTA work (OTA needs two equal sized app partitions to swap between).

### Compile and Upload

1. Open `Supercharger_ESP32S3.ino` in the Arduino IDE.
2. Edit `arduino_secrets.h` with your credentials (see the next section).
3. Plug the controller into your computer with a USB-C cable.
4. Select the correct port under Tools > Port.
5. Click Upload.

First upload over USB takes a minute or two. After that, you can push updates over the air via `/update` without needing the cable.

### Note on "Erase All Flash Before Sketch Upload"

This one is optional. It's Enabled in the table above because the original build had some early development issues that were solved by clean flashes. It's not a requirement for the firmware to work, and you can safely set it to Disabled if you prefer.

What the setting does: when Enabled, every USB upload wipes all flash including NVS, which is where saved WiFi credentials live. The controller will come back up in AP mode after every upload, and you'll have to redo the WiFi setup page each time. That gets old fast.

Set it to Disabled for a smoother dev loop. Just be aware that old NVS state can become incompatible with new firmware if you ever change the structure of what's stored.

Either way, OTA updates via the web don't touch NVS, so WiFi credentials survive OTA fine.

### ESP32 Arduino Core Version

This firmware has been developed and tested against recent versions of the Espressif ESP32 Arduino core. If something fails to compile, update your ESP32 core to the latest release via Boards Manager and try again. The TWAI and USB CDC APIs have changed across versions, so old cores may not work.

---

## For Builders: arduino_secrets.h

If you're compiling this yourself, you have to set credentials in `arduino_secrets.h` before flashing. You must create your own values. Don't ship with the defaults.

```
#define SECRET_AP_SSID          "Supercharger"     // this device's own access point name (optional override)
#define SECRET_AP_PASS          "12345678"         // its password (optional override, min 8)
// Legacy names SECRET_SSID / SECRET_PASS still work: the sketch maps them to the AP pair.

#define SECRET_WIFI_SSID        "your-home-wifi"    // the home network the controller joins as a station
#define SECRET_WIFI_PASS        "your-wifi-password"
// Legacy names SECRET_MQTT_SSID / SECRET_MQTT_PASS still work: the sketch maps them to the WiFi pair.
#define SECRET_MQTT_HOST        "192.168.1.100"   // broker IP or hostname
#define SECRET_MQTT_USER        "your-mqtt-user"
#define SECRET_MQTT_BROKER_PASS "your-mqtt-password"

#define SECRET_OTA_USER         "your-ota-username"
#define SECRET_OTA_PASS         "your-ota-password"

#define SECRET_AP_IP            ""   // fixed AP-mode IP, e.g. "192.168.1.50" (optional)
#define SECRET_AP_GATEWAY       ""   // e.g. "192.168.1.1"
#define SECRET_AP_SUBNET        ""   // e.g. "255.255.255.0"
```

These three `SECRET_AP_*` lines are optional — if your copy of `arduino_secrets.h` predates this feature and doesn't have them, the firmware still compiles (they default to empty).

### Requirements

- **WiFi password must be at least 8 characters**. This is an ESP32 limitation, not mine.
- **OTA user and pass are required**. They protect the `/update` endpoint, as well as charge control, so random people on your network can't reflash or set insane charge values, on/with your controller. Pick something you'll remember but isn't trivial. During creation, this was tested with 32+ characters, so should not be a limiting factor.
- **MQTT credentials are optional**. If you don't use Home Assistant, leave them as empty strings. The MQTT client will keep trying, fail quietly, and not affect anything else.
- **`SECRET_WIFI_SSID` (legacy name `SECRET_MQTT_SSID`) can be blank**. If it is, the controller goes straight to AP mode on first boot. You can still set up WiFi through the setup page. If you set up a WiFi network here, it will automatically set this up and try to connect to it.

### Compile-time AP Defaults (`SECRET_AP_SSID` / `SECRET_AP_PASS`, legacy `SECRET_SSID` / `SECRET_PASS`)

`SECRET_AP_SSID` and `SECRET_AP_PASS` (older secrets files: `SECRET_SSID` / `SECRET_PASS`) set the **default AP name and password** the controller falls back to when no home WiFi is reachable. They override the built-in defaults of `Supercharger` / `12345678`.

The full priority order for the AP credentials is:

1. **NVS** — whatever was last saved via the **Settings** page (highest priority).
2. **`SECRET_AP_SSID` / `SECRET_AP_PASS`** — compile-time defaults from `arduino_secrets.h`.
3. **Built-in defaults** — `Supercharger` / `12345678` (used only if both above are blank).

The point is to let a builder ship a unit with a stronger out-of-the-box AP password than `12345678`, without having to walk a new owner through the Settings page on first boot. If you don't care, just leave `SECRET_AP_SSID` blank and you'll get the built-in defaults.

The same 8-character minimum applies to `SECRET_AP_PASS` as to any WiFi password — that's an ESP32 limitation.

### Compile-time Fixed AP IP (`SECRET_AP_IP` / `SECRET_AP_GATEWAY` / `SECRET_AP_SUBNET`)

These bake in a fixed AP-mode IP at compile time (see *Fixed AP IP Address* under WiFi Setup for what the feature does). Defining a non-empty `SECRET_AP_IP` automatically enables the feature; all three must be valid dotted-quad strings. Leave all three `""` to keep the default `192.168.4.1`.

Priority order, same idea as the AP credentials:

1. **NVS** — whatever was last saved via the **Settings** page (highest priority).
2. **`SECRET_AP_*`** — compile-time defaults from `arduino_secrets.h`.
3. **Built-in default** — `192.168.4.1`.

If you've never touched the Settings page fields, the compile-time values are used. The moment you save the Access Point settings from the dashboard, the NVS values take over.

---

## OTA Firmware Updates

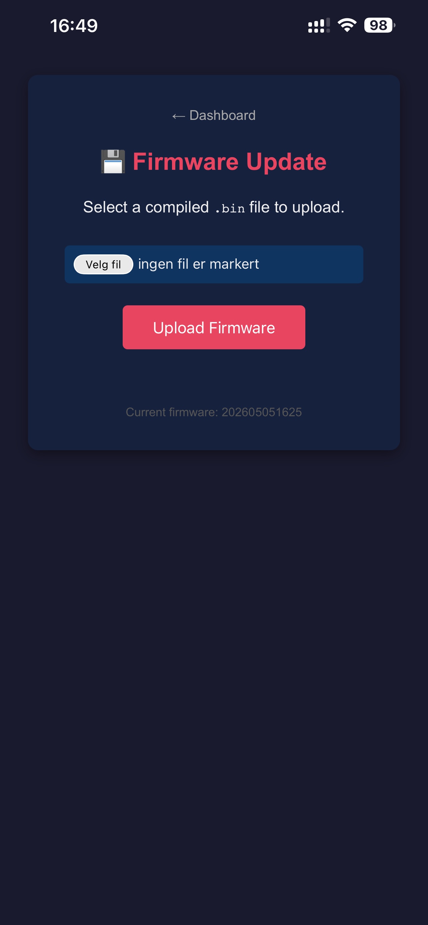
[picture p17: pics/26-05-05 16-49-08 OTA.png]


Once the controller is on your WiFi:

1. Compile a new firmware in the Arduino IDE. Use **Sketch → Export Compiled Binary** or just note the build output path shown in the IDE console.
2. **Pick the right file.** The Arduino IDE 2.x produces two `.bin` files in the build folder:
   - `Supercharger_ESP32S3.ino.bin` — ~1.2 MB. **This is the OTA file.**
   - `Supercharger_ESP32S3.ino.merged.bin` — ~16 MB. This is a full flash image for USB flashing only. Do **not** upload this via the web — it will be rejected.
3. The OTA `.bin` must be **HMAC-signed** before uploading (see below). If you have the post-build hook set up in `platform.local.txt`, this happens automatically every compile.
4. Go to **http://\<controller-ip\>/update** in a browser (or click the OTA link from the dashboard).
5. Log in with your OTA username and password.
6. Select the signed `.bin` file and click Upload.
7. The controller verifies the HMAC signature, flashes the new firmware, and reboots automatically.

If the update fails mid-way, the old firmware is kept. You won't brick the controller unless the flash is cut mid-write (e.g. power loss during upload). If the signature check fails, you'll see **"Update rejected: signature invalid or upload incomplete"** and the controller keeps running the previous firmware unchanged.

### HMAC Signing

Every `.bin` uploaded via the web must carry a 32-byte HMAC-SHA256 trailer produced by `sign_ota.py`. The key lives in `ota_secret.h`. See **BUILD_SETUP.md** in the sketch folder for full setup instructions, including how to install the post-build hook so signing happens automatically on every compile.

If you set up a new build environment (new machine or new Arduino IDE install), re-check that `ota_secret.h` and `sign_ota.py` both contain the same key — a mismatch means the controller will reject every upload until they are resynchronised.

---

## Home Assistant Integration

With MQTT credentials set, the controller auto publishes HA discovery topics under `homeassistant/` whenever it connects. A **Supercharger** device shows up in your HA integrations with the following entities (all auto-created — no YAML required):

### Sensors (read only)

| Entity | Unit | What it is |
| --- | --- | --- |
| `monolith_v` / `monolith_a` | V / A | Monolith pack voltage and current |
| `monolith_tmin` / `monolith_tmax` | °C | Monolith pack min/max cell temperature |
| `monolith_soc` | % | State of charge. Reads directly from the BMS (`0x188` byte 0) once the first status frame arrives — same value as the bike's own dashboard. Falls back to a voltage-curve estimate during the first few seconds after wake-up before any 0x188 has been seen |
| `monolith_ah_avail` | Ah | Available capacity right now: nominal pack AH × current SoC. Tracks "how much charge is actually in the pack" rather than the constant nameplate value. Republishes when it changes by ≥0.5 Ah |
| `powertank_v` / `powertank_a` | V / A | PowerTank pack voltage and current (only published while a PowerTank is detected) |
| `powertank_tmin` / `powertank_tmax` | °C | PowerTank min/max cell temperature |
| `current_power_w` | W | Actual charging power right now. In Bulk this is the commanded power; in Absorption it switches to the real pack power (V×current) since the commanded value tapers to zero there |
| `session_wh` / `session_ah` | Wh / Ah | Energy and charge delivered since the last session reset |
| `target_preset_pct` | % | Active preset percentage (`70`, `80`, `90`, `100`, or `0` if a non-preset custom voltage is set) |
| `thermal_throttle` | — | `"true"` while the hot-cutback is reducing charging power, `"false"` otherwise. Use as a binary template sensor for HA notifications |
| `ramp_phase` | — | Current charging stage: `"bulk"`, `"absorption"`, or `"float"`. Pin to a Lovelace card or use as the trigger for "charging finished" automations (`ramp_phase` transitions to `"float"`) |
| `eta_minutes` | min | Estimated time remaining until the pack reaches the active target voltage. Coulomb-counting estimate during Bulk (smoothed with a 0.2 EMA), absorption-timer countdown during Absorption, `-1` when not charging or the value can't be computed yet (current too low / pack already above target) |
| `cell_balance_mv` | mV | Spread between the highest and lowest individual cell voltage (max − min across all 28 cells). The BMS rotates through cells on CAN frame `0x388`; full coverage takes ~3 s. Not published until at least two cell readings have been received |
| `bms_board_temp` | °C | Temperature of the BMS circuit board (CAN frame `0x488` byte 1 — labelled "Controller Temp" by third-party diagnostic tools). Separate from the cell-interior min/max temperatures in `monolith_tmin` / `monolith_tmax`. Not published until the first `0x488` frame arrives |
| `cycle_count` | — | Total completed charge cycles recorded in the on-device cycle log (`/cycles.csv`). Increments once per session when the controller transitions to Float. Use `state_class: total_increasing` in HA for a running total card |

### Controls (read / write)

| Entity | Type | Range / behavior |
| --- | --- | --- |
| `charging_enabled` | switch | On/off master switch (same as the dashboard ON/OFF button) |
| `target_power_w` | number | Target charging power in watts (0 – 13200) |
| `target_volt_v` | number | Target pack voltage in volts (106.0 – 116.4, 0.1 V steps) — for fine-grained control outside the four presets |
| `charger_count` | number | Scales the dashboard's preset table and power slider max (1 – 4). Does **not** affect what the chargers physically do — see note in Charging Control section. |
| `ramp_rate_wps` | number | Power ramp rate in W per second (10 – 500) |

### Buttons

| Entity | What it does |
| --- | --- |
| `preset_70` | Set target voltage to the **70 %** preset (106.0 V) |
| `preset_80` | Set target voltage to the **80 %** preset (110.0 V) |
| `preset_90` | Set target voltage to the **90 %** preset (113.2 V) |
| `preset_100` | Set target voltage to the **100 %** preset (116.4 V) |
| `reset_session` | Zero the session Wh and Ah counters |

The preset buttons mirror the four buttons on the web dashboard — tap one and the active preset is persisted to NVS, so it survives reboots and OTA updates. `target_preset_pct` updates within ~1 s of the press so you can pin it to a Lovelace card to confirm the new setting.

Device base topic: `supercharger/<hostname>/`. Hostname is the mDNS name (`supercharger` by default).

---

## Troubleshooting

**"No chargers detected" on the dashboard**
Check the 4 pin cable between the chargers and the controller. Confirm the charger CAN bus is at 250 kbps and has 120 Ω termination at both ends. The charger bus is physically separate from the bike bus.
**NOTE:** The Elcon chargers can be shipped both with and without termination. This _can_ work without, but is prone to generate errors in CAN frames. If you have no terminator in the charger end, try to keep the length of wire as short as possible.

**Heartbeat status shows STOPPED**
The controller is sending heartbeat frames but nothing is acking them. Usually means no charger is actually powered up, or a wiring fault on the charger bus.

**Battery data never appears**
Check the bike CAN wiring (GPIO 6 RX, GPIO 7 TX on the ESP32-S3). The bike bus runs at 500 kbps with standard 11 bit IDs. The controller needs at least one BMS0 frame before it shows pack data.

**Can't connect to the Supercharger AP**
Default password is exactly `12345678`, eight characters (or whatever the builder set in `SECRET_AP_PASS`). Some phones cache old passwords, so forget the network and reconnect. The AP broadcasts on 2.4 GHz only.

**Lost WiFi during use**
The controller switches into **AP+STA** mode automatically: it brings up the **Supercharger** AP so the dashboard stays reachable, *and* keeps trying to reconnect to the home network in the background. No power cycle needed. When the home WiFi comes back, STA reassociates on its own and MQTT/Home Assistant resumes. The AP stays up for the rest of the session so you can always reach the unit even if the home network is flaky — power cycle (or the RST button) to drop the AP and go back to STA-only.

Note on channels: when STA reconnects, the SoftAP gets force-moved to the home WiFi's channel (single radio, can't straddle two channels). Phones already connected to the AP on the old channel may briefly drop and reassociate.

**Forgot the IP address**
Try **http://supercharger.local** first — that's mDNS and works on most modern OSes. If that fails (corporate network, multicast disabled, ancient phone), plug in USB-C and check the serial log, or look at your router's DHCP client list.

**Dashboard blank or stuck**
Reload the page. If that doesn't help, check `/log` for errors. You can also power cycle the controller by cutting the 12 V from the chargers.

**Charging is on but nothing is happening — and a red banner is showing**
That's the controller refusing on purpose. See [Status Banners](#status-banners) for what each one means. The short version: too cold, too hot, pack voltage too low, pack temperature unknown, no bike data, a charger reporting a fault, more chargers on the bus than configured, or more than four chargers on the bus. All of them clear themselves once the condition passes — except **Charger fault**, which needs you to press Stop and then Charge again.

**Charging is on, no banner, but the phase says Float**
The pack is already at or above your chosen % preset, so there's nothing to do. Check the % preset row — if the bike is at 84 % and the preset is 80 %, that's expected. Raise the preset and it will start charging within a second. The serial log shows the decision at the point charging was enabled (`no charge needed` vs `BULK`).

**I raised the % preset but it didn't start charging**
If the pack is already within 1 V of the new target, the controller leaves it alone rather than run a whole cycle for under a volt. Pick the next preset up, or wait for the pack to sag. Anything more than 1 V below the new target starts Bulk immediately.

**Charging stops every time it gets cold outside**
Working as intended below 0 °C — see [Cell Protection Limits](#cell-protection-limits). There's no override, deliberately. Warm the pack.

**Power never reaches what I set on the slider**
Check for an amber banner. "At cell current limit" means you've asked for more current than the cells are rated for (1 C) and it's been capped — the pack's capacity, not the chargers, is the constraint. "Pack warm" means thermal cutback. Both are normal.

**"Rebooting…" or other text on a page looks garbled**
Fixed in current firmware — the OTA page was missing its character-set declaration. If you still see it, you're running an older build; reflash.

---

## Technical Reference

### WiFi Boot Priority and Recovery

**Boot-time STA priority:**

1. Saved credentials (set via the setup page, stored in NVS)
2. Compile-time secrets (`SECRET_WIFI_SSID` / `SECRET_WIFI_PASS`, legacy `SECRET_MQTT_SSID` / `SECRET_MQTT_PASS`)

Each attempt has a 15 second timeout before falling through.

**If both fail (or STA drops at runtime):** the controller switches to **AP+STA** mode. The SoftAP comes up immediately so the dashboard stays reachable on the local hotspot, while the STA continues retrying the saved/secret credentials in the background. The Arduino-ESP32 driver auto-reconnects on its own; the firmware also nudges it every 30 s as a safety net.

**AP teardown:** once the STA reconnects and stays up for **90 s continuously**, the controller drops the SoftAP and returns to STA-only (`STATE_CONNECTED`). The "No WiFi" banner clears at that point. If the STA drops again inside the 90 s grace window, the timer resets and the AP keeps serving until the next stable window. This prevents the AP from staying broadcast forever after a brief outage, while still giving you a window to finish whatever you were doing on the hotspot.

**If no STA credentials exist anywhere** (fresh unit, no NVS, blank `SECRET_WIFI_SSID`): the controller goes straight to AP-only setup mode. There's nothing to retry until you provide credentials via the setup page.

**Worst-case time to a usable AP:** about 30 seconds on first boot (prefs fail → secrets fail → AP+STA comes up). Subsequent retries happen in the background without blocking the dashboard.

**State summary:**

| State | STA | AP | When |
| --- | --- | --- | --- |
| `STATE_CONNECTING` | trying | off | Initial boot, attempting STA |
| `STATE_CONNECTED` | up | off | STA succeeded, no fallback needed |
| `STATE_AP_RETRYING` | retrying / up | up | STA failed or dropped; AP visible, STA reconnects in background. AP is torn down automatically after STA has been continuously up for 90 s, returning to `STATE_CONNECTED` |
| `STATE_SETUP_MODE` | n/a | up | No credentials anywhere; waiting for user provisioning |

### CAN Buses

| Bus | Interface | Pins | Speed | IDs |
| --- | --- | --- | --- | --- |
| Bike | ESP32-S3 TWAI | RX=GPIO 6, TX=GPIO 7 | 500 kbps | 11 bit |
| Charger | MCP2515 over SPI | CS=10, SCLK=12, MOSI=11, MISO=13, RST=9 | 250 kbps | 29 bit extended |

### Key Parameters

- Heartbeat frame (controller to charger): ID `0x1806E5F4`, 1 Hz. Stops when charging is disabled.
- Ramp rate: 50 W per 1 second tick.
- Max charge voltage: 116.4 V (1164 dV) — set by the highest threshold in the voltage cutback table (`battery_tables.h`). At 116.4 V the cutback table limits charging to 0.005 C (~570 mA on a 114 Ah pack), effectively a CV trickle finish.
- Max total power: 13200 W (4 chargers at 3300 W each).
- Max charge current: **1.0 C** of BMS-reported pack Ah, applied to total pack current before per-charger division. From the Farasis cell rating (25 A on a 25 Ah cell). Independent of the cutback tables.
- Charging temperature window: **0 to 45 °C**, hard inhibit outside it, with 2 °C hysteresis on re-arm.
- Charge-inhibit voltage floor: **70.0 V** (700 dV, 2.5 V/cell).
- Pack voltage plausibility window: **42.0 to 117.6 V** (420–1176 dV, 1.5–4.2 V/cell). Readings outside this are discarded as corrupt CAN frames.
- BMS staleness timeout: **5 s** without a monolith voltage frame → charger STOP.
- Charger timeout: **10 s** without a status frame → charger marked absent and the count recomputed.
- Max chargers commanded: **4**. More than that on the bus raises a red banner and the count is clamped.

### Cell Specification

Zero monolith cells, for reference when reading `battery_tables.h`:

| Parameter | Value |
| --- | --- |
| Cell | Farasis IMP06160230P25A, NMC pouch |
| Capacity | 25 Ah nominal, 23.5 Ah minimum |
| Configuration | 28 series |
| Nominal voltage | 3.65 V/cell (102.2 V pack) |
| Constant-voltage range | 4.15–4.20 V/cell |
| Discharge minimum | 2.00 V/cell |
| Max charge current | 25 A (1.0 C) |
| Charging temperature | 0 to 45 °C |
| Operating temperature | −20 to 60 °C (discharge; charging is narrower) |

Note that the cutback tables in `battery_tables.h` are capped at 1.0 C to match the cell rating. Earlier firmware allowed table entries up to 3.0 C; the system power ceiling (~1 C at this pack size) meant they never actually bound, but the tables no longer imply headroom that the cells don't have.

---

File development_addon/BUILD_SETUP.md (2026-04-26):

# Build setup — secrets, OTA signing, gitignore

This sketch ships with two firmware-side secrets that must NEVER be
committed to a public repository:

| File | Contents |
|---|---|
| `arduino_secrets.h` | WiFi / MQTT / dashboard-OTA credentials |
| `ota_secret.h` | 32-byte HMAC-SHA256 key for signed OTA |

The `sign_ota.py` script in this folder also contains the HMAC key in plain
text and must be treated identically.

Each of these files is generated locally on the build host and intentionally
varies per host — your HMAC key should not be the same as anyone else's.

## 1. Rotating the OTA key

Generate a new 32-byte hex string with `openssl rand -hex 32`, then update
**both** of:

- `OTA_HMAC_SECRET[32]` in `ota_secret.h` (32 comma-separated `0xNN` bytes)
- `OTA_HMAC_SECRET = bytes.fromhex("...")` in `sign_ota.py`

If they get out of sync, the firmware will reject every OTA upload — including
the one you're trying to deploy *to fix the mismatch*. Test locally before
flashing remotely.

## 2. Auto-sign every build (Arduino IDE)

You don't want to remember to run `python sign_ota.py` after each compile.
Set up a post-build hook so it runs automatically.

1. Find your installed ESP32 core's `platform.txt`. On Windows it's typically
   `%USERPROFILE%\AppData\Local\Arduino15\packages\esp32\hardware\esp32\<version>\platform.txt`.

2. In the **same directory** as that `platform.txt`, create or append to
   `platform.local.txt`:

   ```
   recipe.hooks.objcopy.postobjcopy.99.pattern=python "{build.source.path}/sign_ota.py" "{build.path}/{build.project_name}.bin"
   ```

   Notes:
   - The `99.` is the hook ordering — pick any number that doesn't collide
     with existing hooks. 99 is high enough to run after all the core's own
     post-objcopy steps.
   - `{build.source.path}` resolves to the sketch directory (where
     `sign_ota.py` lives), `{build.path}` is the temporary build output dir,
     `{build.project_name}` is `Supercharger`.

3. Restart the Arduino IDE so it re-reads `platform.local.txt`.

4. Compile any sketch. You should see a line like
   `[sign_ota] .../Supercharger.ino.esp32s3.bin: appended 32 byte HMAC ...`
   in the build output. The `.bin` on disk is now signed.

5. Upload via `/update` as normal. The firmware will accept the signed image
   and reject any unsigned (or wrong-signed) `.bin`.

## 3. Verifying the hook works

Easy sanity check: build, then try uploading an *unsigned* `.bin` via `/update`.  
The dashboard should report `Update rejected: signature invalid or upload incomplete.` and the device  
should keep running the previous firmware unchanged.

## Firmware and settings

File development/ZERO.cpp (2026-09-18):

#include "ZERO.h"

Zero::Zero(){

}

Zero::~Zero(){

}

byte Zero::messageLength=ZERO_MESSAGE_LENGTH;

byte Zero::hasVoltage(short &canId){
  if(canId == CALEX_CHARGE_CONTROL.id
    || canId == BMS_CELL_VOLTAGE.id
    || canId == BMS1_CELL_VOLTAGE.id ) {

      return 1;

  }
    return 0;
}

byte Zero::hasMonolithVoltage(short &canId){
  if(canId == BMS_CELL_VOLTAGE.id) {

      return 1;

  }
    return 0;
}

byte Zero::hasPowerTankVoltage(short &canId){
  if(canId == BMS1_CELL_VOLTAGE.id ) {

      return 1;

  }
    return 0;
}

byte Zero::hasAmps(short &canId){
  if(canId == BMS_PACK_ACTIVE_DATA.id
    || canId == BMS1_PACK_ACTIVE_DATA.id ) {

      return 1;

  }
    return 0;
}

byte Zero::hasMonolithAmps(short &canId){
  if(canId == BMS_PACK_ACTIVE_DATA.id) {

      return 1;

  }
    return 0;
}

byte Zero::hasPowerTankAmps(short &canId){
  if(canId == BMS1_PACK_ACTIVE_DATA.id) {

      return 1;

  }
    return 0;
}

byte Zero::hasMaxCRate(short &canId){
  if(canId == BMS_PACK_TIME.id
    || canId == BMS1_PACK_TIME.id ) {

      return 1;

  }
    return 0;
}

byte Zero::hasMonolithMaxCRate(short &canId){
  if(canId == BMS_PACK_TIME.id) {

      return 1;

  }
    return 0;
}

byte Zero::hasPowerTankMaxCRate(short &canId){
  if(canId == BMS1_PACK_TIME.id) {

      return 1;

  }
    return 0;
}

byte Zero::hasPackTime(short &canId){
  if(canId == BMS_PACK_TIME.id
    || canId == BMS1_PACK_TIME.id ) {

      return 1;

  }
    return 0;
}

byte Zero::hasMonolithPackTime(short &canId){
  if(canId == BMS_PACK_TIME.id) {

      return 1;

  }
    return 0;
}

byte Zero::hasPowerTankPackTime(short &canId){
  if(canId == BMS1_PACK_TIME.id) {

      return 1;

  }
    return 0;
}

byte Zero::hasPackConfig(short &canId){
  if(canId == BMS_PACK_CONFIG.id
    || canId == BMS1_PACK_CONFIG.id ) {

      return 1;

  }
    return 0;
}

byte Zero::hasMonolithPackConfig(short &canId){
  if(canId == BMS_PACK_CONFIG.id) {

      return 1;

  }
    return 0;
}

byte Zero::hasPowerTankPackConfig(short &canId){
  if(canId == BMS1_PACK_CONFIG.id) {

      return 1;

  }
    return 0;
}

byte Zero::hasPackActiveData(short &canId){
  if(canId == BMS_PACK_ACTIVE_DATA.id
    || canId == BMS1_PACK_ACTIVE_DATA.id ) {

      return 1;

  }
    return 0;
}

byte Zero::hasMonolithPackActiveData(short &canId){
  if(canId == BMS_PACK_ACTIVE_DATA.id) {

      return 1;

  }
    return 0;
}

byte Zero::hasPowerTankPackActiveData(short &canId){
  if(canId == BMS1_PACK_ACTIVE_DATA.id) {

      return 1;

  }
    return 0;
}

byte Zero::hasThrottle(short &canId){
  if(canId == CONTROLLER_RPM_THROTTLE_MOT_TEMP.id) {

      return 1;

  }
    return 0;
}

// BMS_PACK_STATUS (0x188 / 0x189) — SoC % at byte 0 (uint8 0..100).
// See ZERO.h for the full byte layout.  The matching frame from the
// secondary "PowerTank" pack uses ID 0x189.
byte Zero::hasPackStatus(short &canId){
  if(canId == BMS_PACK_STATUS.id
    || canId == BMS1_PACK_STATUS.id ) {

      return 1;

  }
    return 0;
}

byte Zero::hasMonolithPackStatus(short &canId){
  if(canId == BMS_PACK_STATUS.id) {

      return 1;

  }
    return 0;
}

byte Zero::hasPowerTankPackStatus(short &canId){
  if(canId == BMS1_PACK_STATUS.id) {

      return 1;

  }
    return 0;
}

// All raw-byte decoders below: validate `len` before reading. CAN frames are
// nominally 8 bytes, but a malformed / short frame from a buggy node — or
// stack garbage in the driver's buffer past `len` — would otherwise yield
// random values that get fed straight into the charging algorithm.
// A 0 return on a short frame is a safe-ish "ignore" for accumulators and
// thresholding (rampTask treats 0/uninitialised pack values as "skip tick").

short Zero::throttle(byte &len,byte buf[ZERO_MESSAGE_LENGTH]){
  if (len < 6) return 0;
  ByteToShort throttleVoltage;

  throttleVoltage.bytes[0]=buf[4];
  throttleVoltage.bytes[1]=buf[5];

  //Serial.println(throttleVoltage.value);

  return throttleVoltage.value;
}

short Zero::amps(byte &len,byte buf[ZERO_MESSAGE_LENGTH]){
  if (len < 5) return 0;
  ByteToShort amps;

  amps.bytes[0]=buf[3];
  amps.bytes[1]=buf[4];

  //Serial.println(amps.value);

  return amps.value;
}

long Zero::voltage(byte &len,byte buf[ZERO_MESSAGE_LENGTH]){
  if (len < 7) return 0;
  ByteToLong voltage;

  voltage.bytes[0]=buf[3];
  voltage.bytes[1]=buf[4];
  voltage.bytes[2]=buf[5];
  voltage.bytes[3]=buf[6];

  //Serial.println(voltage.value);

  return voltage.value;
}

short Zero::sagAdjust(byte &len,byte buf[ZERO_MESSAGE_LENGTH]){
  if (len < 2) return 0;
  ByteToShort sagAdjust;

  sagAdjust.bytes[0]=buf[0];
  sagAdjust.bytes[1]=buf[1];

  //Serial.println(sagAdjust.value);

  return sagAdjust.value;
}

short Zero::maxCRate(byte &len,byte buf[ZERO_MESSAGE_LENGTH]){
  if (len < 8) return 0;
  ByteToShort CRate;

  // Bytes 0-3 of BMS_PACK_TIME (0x508) are a 32-bit runtime counter.
  // Max charge current reported by BMS is at bytes 6-7 (not 4-5).
  CRate.bytes[0]=buf[6];
  CRate.bytes[1]=buf[7];

  return CRate.value;
}

short Zero::AH(byte &len,byte buf[ZERO_MESSAGE_LENGTH]){
  if (len < 7) return 0;
  ByteToShort AH;

  AH.bytes[0]=buf[5];
  AH.bytes[1]=buf[6];

  //Serial.println(AH.value);

  return AH.value;
}

// Cell-temperature decoders for BMS_PACK_ACTIVE_DATA (0x408) and the BMS1
// equivalent (0x409). Layout, confirmed against the SCv2 reference sketches
// (v2.5 / v2.6 / v3 / 13kw_force) and the original Arduino library:
//
//   byte 1: highest cell temp (signed int8, °C)
//   byte 2: lowest  cell temp (signed int8, °C)
//   byte 3-4: pack amps (signed int16, centiamps) — handled by amps()
//
// The previous "scan all 8 bytes and filter by [-20, 85]" approach was a
// workaround for decoding the wrong CAN ID — 0x488 BMS_PACK_TEMP_DATA, which
// on real bikes carries other BMS internals (cell-balance flags, individual
// sensor positions with 0x7F sentinels, etc.). That filter let random
// non-temperature bytes through (e.g. byte 0xF5 reads as -11°C as int8) and
// produced bogus min readings down around -11..0 °C. Temps now come straight
// off the ACTIVE_DATA frame, same place the working SCv2 sketches use.
//
// 0x7F (127) is the BMS "sensor disconnected" sentinel — guarded against so
// a single dead thermistor doesn't push the max to +127°C.
//
// Both cases below return ZERO_TEMP_INVALID, not 0. Returning 0 was itself a
// failure mode: 0 °C is a perfectly plausible pack temperature, so a dead hot
// thermistor looked like a cold-but-healthy pack — the hot cutback stopped
// limiting power and the 45 °C charge inhibit could never fire. The caller
// stores the sentinel as-is and rampTask treats "temperature unknown" as its
// own inhibit reason.

short Zero::highestTemp(byte &len, byte buf[ZERO_MESSAGE_LENGTH]) {
  if (len < 2) return ZERO_TEMP_INVALID;   // frame too short to hold the byte
  if ((uint8_t)buf[1] == 0x7F) return ZERO_TEMP_INVALID;   // disconnected sensor
  return (short)(int8_t)buf[1];
}
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

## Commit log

2026-04-18 First commit.
    Ready to be used at this stage.
2026-04-21 Implemented functions tied to the LilyGo Boot button.
2026-04-21 Updated manual
    Updated manual with the underside of the LilyGo and the PIN designations for the CAN bus attachments.
2026-04-21 Added a case to the LilyGo
    [supercharger_case_v1.stl]
2026-04-23 Updated charging algo
    Extended voltage sag on higher SoC levels.
    Fixed a bug in the presets storage. voltage presets should now be remembered across reboots.
2026-04-24 bug fixes
    Updated charge code to check SoC before start. Updated AP behaviour. Updated Thermal throttling behaviour with a banner. Added more entitites to MQTT. Updated manual to reflect the changes.
2026-04-25 Bugfixes
    Corrected the BMS CAN temp reading.
    Adjusted the display of various charging stages.
    [ZERO.cpp]
2026-04-25 Added ETA timer
    Added a ETA timer that will guesstimate charging time based on various variables.
2026-04-25 Updated Capacity tile
    Updated Capacity tile to show Available/Total rather than just a static total.
2026-04-25 UX update
    Minor changes to the text in README.md
    Minor changes to the UX of the Dashboard. Color of "Current" now follows "absorption" stage to clarify why it drops below target current. At the same time it switches its calculation to use the power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
2026-04-26 Update README.md
    Added text regarding behaviour of charging to 100%.
2026-05-01 Updated various
    Redid the auth section to a session based one. lockout happes after 5 failed login attempts. locks you out for 15 minutes. This should give a much better UX for legitimate use and still slow down bruteforce attempts. This can be reset using the Boot button so make sure to keep the board in a safe place.
    Updated the settings page to allow you to do some defaults.
2026-05-04 Summary of changes
    Removed a bug in battery_tables.h
    Added a new header file handling the new https portal
    Added new settings: now supporting https. upload your own cert files.
    Changed the login, now as a portal that supports password managers. no need to copy/paste your password from somewhere.
2026-05-04 Update Supercharger.ino
    Added an automatic redirect to dashboard after OTA upload.
    Previous version also updated settings with behavior for when at home and for when on the road. I recommend having charger active for when on the road. in case the wlan ap is being stupidly slow, at 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
2026-05-05 20260505-summary update
    Updated manual with more up-to-date pics and text.
    added a cycle counter and a logfile
    added a download button for the logfile
    -> this is for future development but i need more data in order to get to the next part. everything stays local. this is just for your own use. (i use my own bike for testing and developing on)
2026-05-07 minor changes
    upon user input, increased the font size on the SoC and on the charging button. also made the system section hideable.
    updated manual, clarifying in more detail the point of the charger selection part.
2026-05-14 Summary for 202605101611
    Added Cell Balance tile with data. Added BMS Temp tile. Updated MQTT entities with new data.
2026-05-17 bugfix 202605171312
    Another attempt at fixing the charging curve at 100%. (there might be more adjustments to this one..)
    Also, added average cell voltage information.
2026-05-22 Bugfix and added functionality - 202605221633
    Fixed a displaybug on the power entity in mqtt.
    Added a longer serving session cookie. now it retains your login session for longer and past reboots.
    Added settings for AP mode so you can configure static IP setup.
    Updated manual to reflect the changes.
2026-06-21 security fixes
    Fixed a signed/unsigned bug in find_cutback(). Fixed a bug in cold_cutback function. Fixed a bug in BMS staleness data. Fixed/added a check in thermal protection.
2026-06-26 Security fixes and optimizations
    removed a potential DoS vector, introduced a Per-IP blacklist.
    patched a potential overflow bug.
    Redid the boot flow, introducing memory to connected networks to save time during bootup. (connecting to known networks should perform faster)
2026-07-03 v202607031330: security audit hardening + stability fixes
    Security and stability pass from the 2026-07-03 firmware audit.
    Security:
    - Capped RAW-body collection (8 KB) on all port-80 POST routes plus a
    catch-all guard handler, so unauthenticated oversized bodies can no
    longer be buffered into RAM before the auth check runs. Known residual:
    multipart field values still buffer inside the core WebServer library.
    - Device-wide login backstop: 15 failed logins from any mix of client IPs
    within 60 s locks all new logins for 15 min. Closes the gap where
    rotating source addresses could evict per-IP lockout slots and reset
    their counters. Cleared by BOOT 3-5 s hold, reboot, or auto-expiry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
2026-07-25 Bug and stability fixes
    Fixed Control commands being silently dropped on timeout. Fixed a bus-off detection regression. Fixed a length guard in code. Fixed a 301 redirection bug. Fixed a code overflow in urlDecode. Changed thermal ramp to a complete stop on trigger rather than a ramp-down. (better protection). Fixed a potential issue with charger count. Corrected thermal limitting closer to farasis datasheet limits.
    Added a hard limit on charging temps.
    Added protection for low voltage charging and extreme low voltage charging, with UI notifications. Added changes to logic for charging-when-already-at-limit logic flow. Updated manual with changes.
2026-08-15 Added odometer to mqtt and dash
    Added odometer reference to the dashboard and as an entity in mqtt. I wanted to be able to pay attention to the odometer usage, and since the data is readily available on the can bus, figured why not.
2026-09-18 bug fixes
    Added some additional safety checks. Cleaned up static data not in use. Improved a few of the protection checks. Fixed an issue with https. improved credential safety. + + +...
    [ZERO.cpp]
